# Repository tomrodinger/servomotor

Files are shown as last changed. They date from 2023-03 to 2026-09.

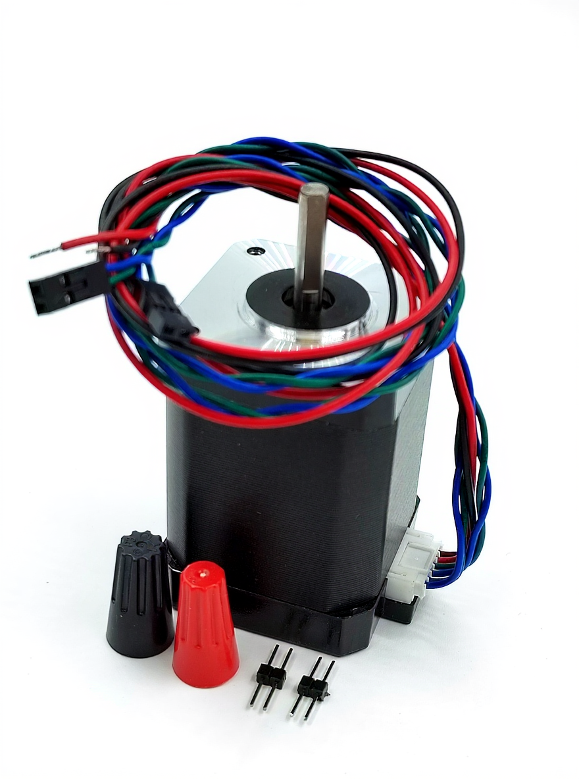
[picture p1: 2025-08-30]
Pictures/servomotor3/ai edited/flux-1-kontext-dev_make_the_background_.png

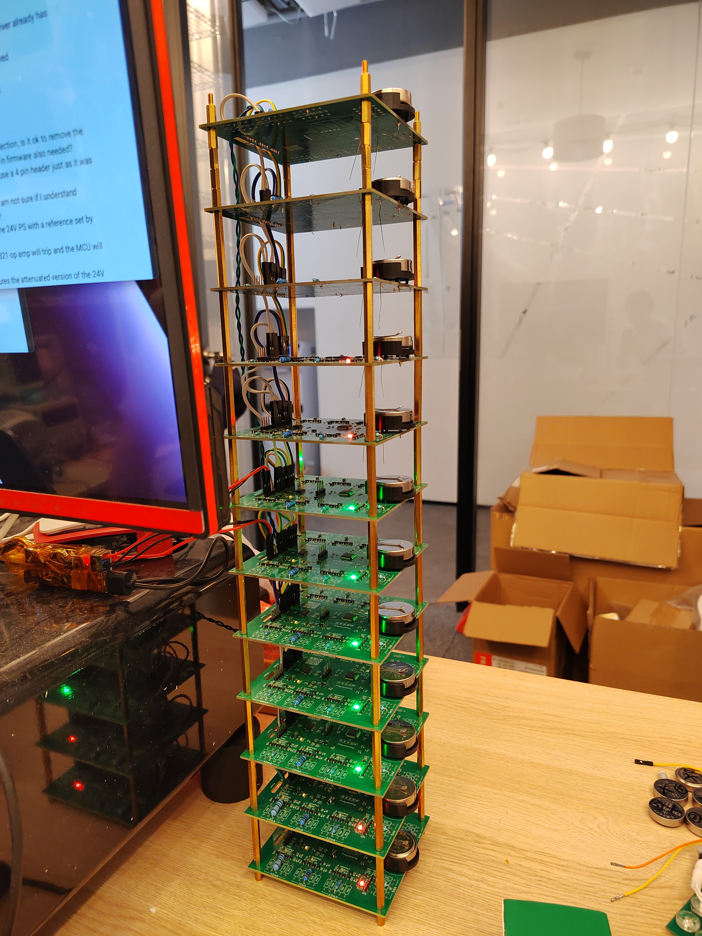
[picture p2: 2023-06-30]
Pictures/coin_cell_tester/side2.jpg

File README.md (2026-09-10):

<p align="center">
  Gearotons M17 servomotor family: M17-60, M17-48, M17-40, M17-34
</p>

# Gearotons M17 — an open-source servomotor you can talk to

The M17 is a NEMA-17 **integrated servomotor**: motor, closed-loop driver, motion controller and
magnetic encoder in one unit. It daisy-chains over RS-485, ships with Python and Arduino libraries,
and has a first-party [MCP server](https://github.com/Gearotons/servomotor-mcp) so an AI assistant
(Claude Desktop, Claude Code, Cursor, …) can drive real motors from plain English.

Hardware, firmware and software are all in this repository under the MIT license.

| | M17-34 | M17-40 | M17-48 | M17-60 |
|---|---|---|---|---|
| Length | 33.5 mm | 40.1 mm | 48.7 mm | 59.7 mm |
| Holding torque | 0.28 N·m | 0.42 N·m | 0.55 N·m | 0.65 N·m |
| Weight | 210 g | 285 g | 360 g | 470 g |

All sizes: 12–24 V, up to ~1.1 A, up to 560 RPM, closed-loop 32 kHz control, RS-485 at 230400 baud,
64-bit unique ID + one-byte alias per motor, standard NEMA-17 mount. Indoor use (IP20).

**Buy one:** [gearotons.com](https://gearotons.com) (from $20; ships worldwide from Shenzhen).
**Documentation:** [9o.at/M17_1.5](https://9o.at/M17_1.5) ·
[Datasheet (PDF)](servomotor_datasheets/datasheet_latest_en.pdf) ·
[Python API](API_documentation/M17_servomotor_Python_API_documentation.md) ·
[Arduino API](API_documentation/M17_servomotor_Arduino_API_documentation.md)

## Quick start (Python)

```bash
pip install servomotor
```

```python
import time, servomotor

servomotor.open_serial_port()                      # prompts for the USB–RS-485 adapter the first time
m = servomotor.M3("X", time_unit="seconds", position_unit="shaft_rotations")
m.enable_mosfets()
m.trapezoid_move(1.0, 1.0)                         # one full turn, in one second
time.sleep(1.1)
m.disable_mosfets()
servomotor.close_serial_port()
```

That is [`python_programs/example_trapezoid_move.py`](python_programs/example_trapezoid_move.py).
Units are yours to choose (degrees, rotations, radians, encoder counts; seconds or milliseconds) —
the library converts. No STEP/DIR timing, no microstep configuration.

## Quick start (Arduino / ESP32)

Install the **Servomotor** library by Gearotons from the Arduino Library Manager, or from
[`Arduino_library/`](Arduino_library/). Wire the board's UART to an RS-485 transceiver, then:

```cpp
#include <Servomotor.h>

void setup() {
  Servomotor motor('X', Serial1);                  // alias 'X'; the port opens on first use
  motor.setPositionUnit(PositionUnit::SHAFT_ROTATIONS);
  motor.setTimeUnit(TimeUnit::SECONDS);
  motor.enableMosfets();
  motor.trapezoidMove(2.0f, 3.0f);                 // two rotations over three seconds
  delay(4000);
  Serial.println(motor.getPosition());             // where it actually is, from the encoder
}
void loop() {}
```

That is a trimmed [`Arduino_library/example_one_move.cpp`](Arduino_library/example_one_move.cpp)
(the full file adds the ESP32 RS-485 pin definitions).

## Quick start (talk to it)

```bash
uvx --from servomotor-mcp servomotor-mcp        # runs with a simulated motor if no hardware is attached
```

Add it to Claude Desktop or run `claude mcp add gearotons-motor -- uvx --from servomotor-mcp servomotor-mcp`,
then ask: *"Find my motors, then move the one on the bench to 90 degrees and tell me where it ended up."*
Details and the full tool list: [Gearotons/servomotor-mcp](https://github.com/Gearotons/servomotor-mcp).

<p align="center">
  Claude Code driving a real M17 over MCP: find the motor, turn it two rotations, back, read the encoder
</p>
<p align="center"><a href="https://github.com/Gearotons/servomotor-mcp/releases/download/v0.3.1/M17-claude-code-demo.mp4">▶ 50-second video: the real motor and this session side by side</a> (recorded 2026-09-09 on a bench M17).</p>

<p align="center">
  Wiring: computer, USB to RS-485 adapter, two daisy-chained M17 motors, 12–24 V supply
</p>

## What is in this repository

| Folder | Contents |
|---|---|
| [`firmware/`](firmware/) | Motor firmware (STM32G0), plus [`bootloader_STM32G030/`](bootloader_STM32G030/) and [`bootloader_STM32G031/`](bootloader_STM32G031/) |
| [`PCB/`](PCB/) | Schematics, board layouts and 3D (STEP) models of the controller board |
| [`python_programs/`](python_programs/) | The `servomotor` Python library source, examples, test and characterisation scripts |
| [`Arduino_library/`](Arduino_library/) | The Arduino/ESP32 C++ library and examples |
| [`API_documentation/`](API_documentation/) | Generated Python and Arduino API references (Markdown and PDF) |
| [`servomotor_datasheets/`](servomotor_datasheets/) | Datasheet sources and PDFs (EN, DE, ES, FR, IT, PT), dimension drawings |
| [`production_test_system/`](production_test_system/), [`motor_tests/`](motor_tests/) | How we test motors before they ship |
| [`marketting_page/`](marketting_page/) | Source of the gearotons.com product page |

The command set is data-driven: every firmware command is defined once in
[`motor_commands.json`](python_programs/servomotor/motor_commands.json) and the Python library, the Arduino library and the MCP server are generated
from it, so they always agree.

## Where the M17 is not the right tool

Direct-drive torque tops out at 0.65 N·m (gear it or go up a frame size for more), it is IP20 and
indoor-only, and it is not a STEP/DIR drop-in for an existing 3D-printer board — it wants a serial
bus and a host that sends it moves. We would rather you know that before you buy.

## Community and support

Questions and builds: [GitHub Discussions](https://github.com/tomrodinger/servomotor/discussions) ·
email [info@gearotons.com](mailto:info@gearotons.com). Issues and pull requests welcome — the whole
stack is here to be read, modified and improved.

Built and assembled by Gearotons in Shenzhen. MIT license — see [LICENSE](LICENSE).

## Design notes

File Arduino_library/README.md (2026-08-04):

# Project Overview

> **Documentation Note**: All project documentation is maintained in this README.md file. Whenever documentation is mentioned or requested, it refers to updates or additions to this file.

This project provides a C++ library for controlling servo motors on both embedded platforms (Arduino, ESP32-C3, etc.) and desktop environments (macOS, etc.). It includes:

- **Minimal Arduino emulator** for desktop testing (`ArduinoEmulator.h`).
- **Auto-generated unit conversions** for positions, velocities, times, temperatures, etc. (`AutoGeneratedUnitConversions.*`).
- **Servomotor** class for motor control with advanced features like calibration, homing, e-stop, etc.
- **Example test programs**: `test_one_move.cpp`, `test_unit_conversions.cpp`, and `test_get_temperature.cpp`.

## Autogeneration of Parts of the Source Code

The library includes several Python scripts for code generation and maintenance:

- `generate_unit_conversion_code.py`: Generates unit conversion code from a JSON configuration
- `generate_command_code.py`: Generates command interface code

## File List and Descriptions

Below is an updated overview of the key files after renaming and restructuring:

| File | Description |
|---|---|
| **ArduinoEmulator.h** | Emulates Arduino's `Serial`, `delay()`, etc. for desktop builds. |
| **AutoGeneratedUnitConversions.h / .cpp** | Functions to convert between various units (time, position, velocity, acceleration, etc.). |
| **Commands.h** | Autogenerated list of servo command IDs. |
| **Communication.h / .cpp** | Simple `Communication` class for sending/receiving commands (stubbed for testing). |
| **DataTypes.h / .cpp** | Definitions of data type structures and bounds. |
| **Utils.h / .cpp** | Helper utilities for endianness, packing, and general-purpose functionality. |
| **Servomotor.h / .cpp** | Main servo control class with features like calibration, homing, e-stop, etc. |
| **test_one_move.cpp** | Minimal example demonstrating a single trapezoid move (2 rotations over 3 seconds). |
| **test_unit_conversions.cpp** | Desktop test verifying unit-conversion logic in `AutoGeneratedUnitConversions.*`. |
| **test_get_temperature.cpp** | Example demonstrating how to read temperature from the motor. |
| **test_emergency_stop.cpp** | Test for emergency stop functionality to ensure proper queue clearing and MOSFET disabling. |
| **test_move_with_velocity.cpp** | Test for moveWithVelocity functionality with different units (rotations, degrees, encoder counts). |
| **test_enable_disable_mosfets.cpp** | Test for enabling and disabling MOSFETs. |
| **test_one_move_two_motors.cpp**  | Example demonstrating control of two motors simultaneously. |

## Architecture

1. **Unit Conversion Module**  
   - Centralizes all unit transformations in `AutoGeneratedUnitConversions.*`, ensuring consistency.
   - Supports various units:
     - Position: SHAFT_ROTATIONS, DEGREES, RADIANS, ENCODER_COUNTS
     - Time: SECONDS, MILLISECONDS, MINUTES, TIMESTEPS
   - Automatic conversion between user units and internal units (encoder counts and timesteps)

3. **Communication Module**  
   - `Communication.cpp` is a lightweight stub for sending commands and reading responses. It can be extended or replaced with a hardware-specific protocol (RS-485, UART, etc.).

4. **Servo Control Class**  
   - **`Servomotor`** provides:
     - Automatic unit conversions between user units and internal units
     - Detailed debug output for all operations
     - Automatic serial port initialization
     - User-friendly interface for motor control

5. **Testing on Desktop vs. Arduino**  
   - If `ARDUINO` macros are defined, `<Arduino.h>` is used for real hardware.  
   - Otherwise, `ArduinoEmulator.h` provides stubs for Serial/delay so the same code builds on desktop.  
   - **Test programs** can be built via a standard C++ compiler on desktop or compiled as `.ino`/C++ sources on an Arduino platform.

## RS485 Communication Protocol

The library implements a robust RS485 communication protocol for reliable communication between a controller (master) and one or more devices (slaves). The protocol supports both standard addressing (using device aliases) and extended addressing (using 64-bit Unique IDs).

### Packet Format

All packets follow this basic structure:

1. **Size Bytes**: First byte(s) indicating total packet size
   - For sizes 1-127: Single byte containing size (left-shifted 7 bits with LSB=1)
   - For sizes >127: Three bytes
     - First byte: `0xFF` (encoded value of 127 with LSB=1)
     - Two additional bytes: Little-endian 16-bit size

2. **Address Bytes**:
   - **Standard Addressing**: Single byte containing device alias
     - `255` (`ALL_ALIAS`): Broadcasts to all devices
     - `254` (`EXTENDED_ADDRESSING`): Indicates extended addressing mode
     - `253` and `252` are not allowed because they are used to indicate responses (see below)
     - `0-251`: Normal device aliases
   - **Extended Addressing**: When address byte is `254`, next 8 bytes contain 64-bit Unique ID (little-endian)

3. **Command Byte**: 8-bit command identifier

4. **Payload Data**: Variable length data specific to the command

5. **CRC32**: Optional 4-byte CRC32 checksum (enabled by default but can be disabled)

### Response Format

Responses from devices follow this structure:

1. **Size Bytes**: Same format as command packet

2. **Response Character**: Single byte indicating response and CRC32 state
   - `253` (`RESPONSE_CHARACTER_CRC32_ENABLED`): Response from device with CRC32 enabled
   - `252` (`RESPONSE_CHARACTER_CRC32_DISABLED`): Response from device with CRC32 disabled

3. **Command Byte**: 8-bit value indicating status
   - `0`: Success and there is no firther data in the response
   - `1`: Success and there is some further data in the response
   - Other values: Currently not used and reserved for future use

4. **Payload Data**: Variable length response data

5. **CRC32**: Optional 4-byte checksum (enabled by default but can be disabled)

### CRC32 Implementation

CRC32 checksums provide additional data integrity verification:

- Uses polynomial 0xEDB88320
- Initialized to 0xFFFFFFFF
- Calculated over entire packet contents (including size, address/response character, command, and payload bytes)
- Final value is inverted to get the final CRC32 value
- The CRC32 calculation gives the same result as Pythons zlib.crc32() or binascii.crc32() functions

- Control:
  - Enabled by default after device reset
  - Can be enabled or disabled on a per-device basis by sending a `CRC32_CONTROL_COMMAND`
  - The response has encoded in it whether the device has appended a CRC32 in the response or not
  - Error statistics can be retrieved by issuing a `GET_CRC32_ERROR_COUNT_COMMAND` to the device

### Error Handling

The protocol includes robust error handling with specific error codes. The `Communication` class functions (particularly `getResponse`) return specific negative error codes on failure, or `COMMUNICATION_SUCCESS` (0) on success:

- `COMMUNICATION_ERROR_TIMEOUT` (-1): Timed out waiting for reply bytes. The 1-second budget covers the WHOLE reply, not each byte, and the stages it can expire in are: the first size byte, the extended size bytes, the response character, the device error byte, the payload, and the CRC32 (if enabled). A broadcast (alias 255) also produces this, because broadcasts are never answered.
- `COMMUNICATION_ERROR_DATA_WRONG_SIZE` (-2): The reply's payload length did not match what the command expects
- `COMMUNICATION_ERROR_BAD_RESPONSE_CHAR` (-3): The response character byte was not `RESPONSE_CHARACTER_CRC32_ENABLED (253)` or `RESPONSE_CHARACTER_CRC32_DISABLED (252)`
- `COMMUNICATION_ERROR_BUFFER_TOO_SMALL` (-5): Your buffer was smaller than the payload the device sent. For the variable-length calls the required size is reported back through `actualSize`, so you can resize and retry
- `COMMUNICATION_ERROR_CRC32_MISMATCH` (-6): Calculated CRC32 of the received response did not match the received CRC32 value (when CRC enabled)
- `COMMUNICATION_ERROR_BAD_FIRST_BYTE` (-7): The first byte of a received packet did not have LSB=1, indicating a format error or corrupted data
- `COMMUNICATION_ERROR_PACKET_TOO_SMALL` (-9): The declared packet length was too small to be a valid reply

Two further macros exist in `Communication.h` but are never returned by any code path, so do not write handlers for them: `COMMUNICATION_ERROR_BAD_STATUS_CHAR` (-4) and `COMMUNICATION_ERROR_BAD_THIRD_BYTE` (-8). (-8 in particular described a "Command Byte" in the response; replies contain no command byte.)

### Buffer Handling

When using the Arduino library's `getResponse` function for commands that do not return any payload data, `nullptr` can be passed as the buffer. The library will still receive and validate the full response (including CRC32 check if applicable) but will not attempt to copy the (empty) payload.

### Command Processing Flow

1. Controller sends command packet
2. Device receives and processes command
3. Device sends response packet (if required)
4. Controller receives and validates response

### Communication Class Methods

The `Communication` class provides the following key methods:

- `Communication(HardwareSerial& serialPort)`: Constructor, requires a `HardwareSerial` port (e.g., `Serial1`)
- `sendCommand(uint8_t alias, uint8_t commandID, const uint8_t* payload, uint16_t payloadSize)`: Sends a command using standard alias addressing
- `sendCommandByUniqueId(uint64_t uniqueId, uint8_t commandID, const uint8_t* payload, uint16_t payloadSize)`: Sends a command using extended 64-bit Unique ID addressing
- `getResponse(uint8_t* buffer, uint16_t bufferSize, uint16_t& receivedSize)`: Waits for, receives, validates, and processes a response packet from a device. Returns `COMMUNICATION_SUCCESS` or a negative error code. Fills `buffer` with payload and `receivedSize` with payload length on success
- `enableCRC32() / disableCRC32()`: Manages the library's expectation of whether CRC32 should be included in *outgoing* commands. Note: The library automatically updates its internal CRC state based on the response character received from the device
- `isCRC32Enabled()`: Returns true if the library currently expects CRC32 to be used
- `flush()`: Discards any unread incoming serial data and waits for outgoing data to finish transmitting

## Installation

1. Download the Arduino library
2. Import it into the Arduino IDE
3. Include the library in your project by including "Servomotor.h"

## Example Usage

A typical Arduino `.ino` or `.cpp` file might look like:

```cpp
#include "Servomotor.h"

void setup() {
  Serial.begin(115200);  // For debug output

  // Create a Servomotor instance (note the lower-case 'm' - ServoMotor with a
  // capital M is a different, unrelated Arduino library)
  Servomotor motor('X', Serial1);  // Initialize with alias 'X' and Serial1 port
  
  // Set desired units (debug output will show the conversions)
  motor.setPositionUnit(PositionUnit::SHAFT_ROTATIONS);
  motor.setTimeUnit(TimeUnit::SECONDS);
  
  // Move 2 rotations over 3 seconds
  motor.trapezoidMove(2.0f, 3.0f);
}

void loop() {
  // ...
}
```

The debug output will show:
```
[Motor] Initialized with standard addressing, Alias: 88
[Motor] setPositionUnit called
[Motor] setTimeUnit called
[Motor] trapezoidMove called.
  displacement in chosen unit: 2.00
  duration in chosen unit: 3.00
[Motor] trapezoidMoveRaw called.
```

Two things to note about this output. The alias prints as its decimal character
code, so `'X'` appears as `88`. And a unit-converting call such as
`trapezoidMove()` prints several lines, because the wrapper echoes each argument
and then calls the internal `...Raw()` variant, which prints as well.

These messages are printed unconditionally by every command; there is currently no
compile-time flag to switch them off. Bear that in mind before putting a command
inside a fast polling loop.

### Checking whether a command actually worked

No command method returns a success flag. Each one records the outcome of its last
exchange with the motor, and you read it with `getError()`:

```cpp
motor.enableMosfets();
if (motor.getError() != 0) {
  Serial.print("enableMosfets failed, getError() = ");
  Serial.println(motor.getError());
}
```

`getError()` returns `0` on success, a **positive** value that is the motor's own
fatal error code, or a **negative** value for a host-side communication failure
(`-1` is a timeout: wrong alias, wrong pins, motor unpowered, or motor in the
bootloader). This matters because a motor that has latched a fatal error disables
itself and silently ignores every later command except *Get status* and
*System reset* — your sketch keeps running normally and the motor simply stops
moving.

Watch out for one trap: when a read fails, the getters return a zero-initialised
default rather than an error value. `Serial.println(motor.getHallSensorPosition())`
printing `0.00` can mean "the call failed", not "the shaft is at zero". Always check
`getError()` before trusting a returned value.

See the *Arduino Essentials* section of the Servomotor Arduino API documentation
for the full treatment, including the recommended startup sequence.

### Important Usage Notes

**Using moveWithVelocity and moveWithAcceleration:**
When using moveWithVelocity or moveWithAcceleration, you must queue a second move to stop the motor properly. If the final velocity is not zero when the queue becomes empty, the motor will trigger a fatal error.

Example with moveWithVelocity:
```cpp
// First move at desired velocity
motor.moveWithVelocity(2.0f, 1.0f);  // 2 rotations/sec for 1 second

// Then queue a stop command
motor.moveWithVelocity(0.0f, 0.1f);  // 0 rotations/sec for 0.1 seconds
```

Example with moveWithAcceleration:
```cpp
// First move with positive acceleration
motor.moveWithAcceleration(2.0f, 1.0f);  // 2 rotations/sec² for 1 second

// Then queue a move with negative acceleration to stop
motor.moveWithAcceleration(-2.0f, 1.0f);  // -2 rotations/sec² for 1 second
```

**Using multiMove for Complex Motion Sequences:**
The multiMove function allows you to queue multiple velocity and acceleration moves in a single command. This is useful for creating complex motion sequences without having to send multiple commands.

There are two versions of the multiMove function:
- `multiMove`: Handles unit conversions based on your configured units
- `multiMoveRaw`: Uses raw internal units without conversion

The library provides two structures for defining move sequences:
1. `multiMoveListConverted_t`: For user-friendly units with floating-point values
   ```cpp
   typedef struct {
       float value;       // velocity or acceleration in user units
       float duration;    // duration in user units (seconds, milliseconds, etc.)
   } multiMoveListConverted_t;
   ```

2. `multiMoveList_t`: For raw internal units
   ```cpp
   typedef struct {
       int32_t value;     // acceleration or velocity value (internal units)
       uint32_t timeSteps; // duration in time steps (internal units)
   } multiMoveList_t;
   ```

Example with multiMove (using user units):
```cpp
// Create a sequence of moves
const uint8_t multiMoveCount = 4;
uint32_t multiMoveTypes = 0b1001;  // 1st and 4th are velocity moves, 2nd and 3rd are acceleration moves

// Create move list with user units
multiMoveListConverted_t multiMoveList[multiMoveCount] = {
    {2.0f, 1.0f},    // Velocity move: 2 rot/sec for 1 sec
    {2.0f, 1.0f},    // Acceleration move: 2 rot/sec² for 1 sec
    {-2.0f, 1.0f},   // Acceleration move: -2 rot/sec² for 1 sec
    {0.0f, 0.1f}     // Velocity move: 0 rot/sec for 0.1 sec (stop)
};

// Execute the multi-move sequence with automatic unit conversion
motor.multiMove(multiMoveCount, multiMoveTypes, multiMoveList);
```

Example with multiMoveRaw (using internal units):
```cpp
// Create a sequence of moves
const uint8_t multiMoveCount = 2;
uint32_t multiMoveTypes = 0b11;  // Both are velocity moves

// Create move list with internal units
// For velocity: CONVERSION_FACTOR_ROTATIONS_PER_SECOND = 109951162.777600005f
// For time: CONVERSION_FACTOR_SECONDS = 31250.000000000f
multiMoveList_t multiMoveList[multiMoveCount] = {
    {219902325, 31250},  // Velocity move: 2 rot/sec for 1 sec in internal units
    {0, 3125}            // Velocity move: 0 rot/sec for 0.1 sec in internal units
};

// Execute the multi-move sequence with raw units
motor.multiMoveRaw(multiMoveCount, multiMoveTypes, multiMoveList);
```

The moveTypes parameter is a 32-bit number where each bit specifies the type of move:
- 0: MOVE_WITH_ACCELERATION
- 1: MOVE_WITH_VELOCITY

For example, 0b1001 means the 1st and 4th moves are velocity moves, while the 2nd and 3rd are acceleration moves.

The last move in a sequence should always set the motor's velocity to 0 for a period of time (e.g., 0.1 seconds) to allow the motor to stop properly. Otherwise, the motor will enter a fatal error state when the queue becomes empty with a non-zero velocity on the motor.

**Expected Position Calculation for Complex Sequences:**
When using a combination of velocity and acceleration moves, the final position can be calculated as follows:

1. Velocity move: distance = velocity × duration
2. Acceleration move:
   - Starting from a non-zero velocity: distance = (initial_velocity × duration) + (0.5 × acceleration × duration²)
   - Final velocity = initial_velocity + (acceleration × duration)

For example, in a sequence like:
```cpp
multiMoveListConverted_t moves[4] = {
    {2.0f, 1.0f},    // Velocity move: 2 rot/sec for 1 sec
    {2.0f, 1.0f},    // Acceleration move: 2 rot/sec² for 1 sec
    {-2.0f, 1.0f},   // Acceleration move: -2 rot/sec² for 1 sec
    {0.0f, 0.1f}     // Velocity move: 0 rot/sec for 0.1 sec (stop)
};
```

The expected position calculation would be:
1. Velocity move: 2 rot/sec × 1 sec = 2 rotations
2. Acceleration move: Starting velocity 2 rot/sec, accelerating at 2 rot/sec²
   - Displacement = (2 rot/sec × 1 sec) + (0.5 × 2 rot/sec² × 1 sec²) = 2 + 1 = 3 rotations
   - Final velocity = 2 + (2 × 1) = 4 rot/sec
3. Acceleration move: Starting velocity 4 rot/sec, decelerating at 2 rot/sec²
   - Displacement = (4 rot/sec × 1 sec) - (0.5 × 2 rot/sec² × 1 sec²) = 4 - 1 = 3 rotations
   - Final velocity = 4 - (2 × 1) = 2 rot/sec
4. Velocity move: 0 rot/sec for 0.1 sec (stop)
   - Displacement = 0 rotations

Total displacement: 2 + 3 + 3 + 0 = 8 rotations

### Testing

The library's test suite lives in **`Servomotor_TestSuite_ESP32S3/`** (see its
README for full details). It contains ~37 modular tests (`tm_*.cpp`, one per
command group, ~580 assertions) that build TWO ways from the same sources:

1. **On-device (primary):** all modules compile into one ESP32-S3 firmware that
   runs natively on the Gearotons ESP32-S3 RS485 controller — one test per
   boot, the ESP32 resets between tests, progress + pass/fail statistics
   persist in NVS, and a serial CLI triggers tests over the debug link.

   ```bash
   cd Servomotor_TestSuite_ESP32S3
   ./flash_suite.sh                 # refresh installed lib + compile + flash
   python3 run_suite_mac.py         # start a full run and collect results
   python3 run_suite_mac.py --only 5   # run a single test by index
   ```

2. **Host mode:** the same modules compile on a desktop against the Arduino
   emulator (`ArduinoEmulator.h`) and talk to a motor through any USB-RS485
   port — no flashing needed, useful for quick iteration and for testing a
   multi-motor bus from the desktop:

   ```bash
   cd Servomotor_TestSuite_ESP32S3
   ./build_host_suite.sh
   ./host_suite /dev/cu.usbserial-XXXX <16-hex-unique-id> all
   ./host_suite /dev/cu.usbserial-XXXX <16-hex-unique-id> multimove   # one test
   ```

Tests marked with known-bug annotations in `test_registry.cpp` assert the
CORRECT behavior and are expected to fail until those library bugs are fixed;
the suite summary counts them separately (`unexpected=0` means a clean run).

## TODO / Upcoming Changes

1. **Unit Conversion Tests to Implement (in order of priority)**
   - test_position_conversions.cpp - Test position unit conversions in:
     - trapezoidMove / trapezoidMoveRaw
     - goToPosition / goToPositionRaw
     - getPosition / getPositionRaw
     - getHallSensorPosition / getHallSensorPositionRaw
     - getComprehensivePosition / getComprehensivePositionRaw
     - Multimove
   
   - test_time_conversions.cpp - Test time unit conversions in:
     - getCurrentTime / getCurrentTimeRaw
     - trapezoidMove (duration parameter)
     - goToPosition (duration parameter)
     - moveWithVelocity (duration parameter)
   
   - test_velocity_conversions.cpp - Test velocity unit conversions in:
     - setMaximumVelocity / setMaximumVelocityRaw
     - moveWithVelocity / moveWithVelocityRaw
   
   - test_acceleration_conversions.cpp - Test acceleration unit conversions in:
     - setMaximumAcceleration / setMaximumAccelerationRaw
     - moveWithAcceleration / moveWithAccelerationRaw
   
   - test_current_conversions.cpp - Test current unit conversions in:
     - setMaximumMotorCurrent / setMaximumMotorCurrentRaw
   
   - test_temperature_conversions.cpp - Test temperature unit conversions in:
     - getTemperature / getTemperatureRaw
   
   - test_limits_conversions.cpp - Test limit unit conversions in:
     - setSafetyLimits / setSafetyLimitsRaw
     - setMaxAllowablePositionDeviation / setMaxAllowablePositionDeviationRaw

3. **Code Generation Enhancements**
   - ✅ Improve the autogeneration program that creates Servomotor.cpp and Servomotor.h
   - ✅ Make the code generation process more maintainable and flexible
   - ✅ Fix the conversion factors for current and voltage in the unit_conversions_M3.json file. Currently, these factors are missing or incorrect, resulting in a factor of 1.0 being used.

3. **Fix Some Problems With Servomotor.cpp, or Rather the Program that Generates this File, Which is generate_command_code.py**
   - ✅ getComprehensivePosition obviously will return zeros, which is wrong. Seems the autogeneration program does not know how to convert this
   - ✅ getMaxPidError has the same problem

4. **Fix the Multimove Function**
   - ✅ Fixed the moveList parameter type by defining a struct for move commands:
     ```cpp
     typedef struct {
         int32_t value;  // acceleration or velocity value (internal units)
         uint32_t timeSteps;  // duration in time steps (internal units)
     } multiMoveList_t;
     ```
   - ✅ Added a new struct for user-friendly units with floating-point values:
     ```cpp
     typedef struct {
         float value;  // velocity or acceleration in user units
         float duration;  // duration in user units (seconds, milliseconds, etc.)
     } multiMoveListConverted_t;
     ```
   - ✅ Implemented two versions of the multiMove function:
     - `multiMoveRaw`: Uses raw internal units without conversion
     - `multiMove`: Handles unit conversions based on configured units
   - ✅ Created example_multi_move.cpp to demonstrate how to use the multiMove function with a sequence of moves
   - ✅ Fixed the expected behavior calculation in example_multi_move.cpp to correctly account for velocity continuity between moves
   - ✅ Verified that the implementation works correctly with unit conversions
   - ✅ Created test_multi_move.cpp test program that extensively tests the multiMove and multiMoveRaw functions with all units for velocity, acceleration, and time
   - ✅ Added helper functions for calculating appropriate delay times for both user units and internal units
   - ✅ Updated documentation with detailed information about the multiMove functions, structures, and expected position calculations
   - ✅ Updated the autogeneration program (../autogeneration/generate_command_code.py) to correctly generate the Servomotor.h and Servomotor.cpp files with proper handling of list_2d type parameters in wrapper functions.
   - ✅ Verified that test_multi_move.cpp compiles and passes after the autogeneration program changes. All tests pass in fact.

5. ✅ **Rename ServomotorCommands.cpp to Servomotor.cpp** (Completed)
   - ✅ Renamed ServomotorCommands.h to Servomotor.h
   - ✅ Updated all tests and programs to use Servomotor.h instead
   - ✅ Updated the generate_command_code.py script to generate the updated filenames

6. **test_unit_conversions test fails, need to fix**
   - one test related to testAccelerationConversions() fails

7. ✅ **Make sure that the copy_stuff_to_Arduino.sh script copies all relevant file for the Arduino library to work**
    - ✅ Updated the script to only copy core library files
    - ✅ Added proper handling of example files (example_one_move.cpp and example_one_move_two_motors.cpp)
    - ✅ Created proper Arduino library directory structure with src/ and examples/ folders

8. **Test the Arduino library on an actual Arduino board such as ESP32-C3**
   - ✅ see if it compiles
   - ✅ see if it can control an actual motor

9. **Create more Arduino examples**
    - Create additional simple examples for common use cases
    - Ensure examples demonstrate best practices for using the library
    - Consider examples for different motor control scenarios

10. **Launch this Arduino library into the Arduino marketplace**
    - Anyone on the internet familiar with the Arduino IDE should be able to get it and easily use it

11. **Revamp the test_unit_conversion.cpp test**
    - this test should do unit conversions in one direction (given unit to internal unit) and in the other direction (internal to given unit)
    - it should check the converted value against the validation numbers in the ../python_programs/servomotor/unit_conversions_M3.json file
    - the test should read in the above json file on the fly to get all units to be tested as well as the validation values

12. **Clean up magic numbers in the tests**
   - ✅ many values look like magic numbers but are just a multiple of the MICROSTEPS_PER_ROTATION, so we should place a #define in the test for the MICROSTEPS_PER_ROTATION and then derive validation number based on this

13. **Revamp how magic numbers are defined in the AutoGeneratedUnitConversions.x files**
   - ✅ Magic numbers should be moved to AutoGeneratedUnitConversions.h and should follow a simular naming convention as in the source file where the data is taken from, which is from the json file that is given as a parameter to generate_unit_conversion_code.py, where currently that file is ../python_programs/servomotor/unit_conversions_M3.json
   AutoGeneratedUnitConversions.cpp should be refined to use the #defines instead of holding the magic numbers within the functions.
   - ✅ For conversion that are more complex than multiplying or dividing by a scaling factor (temperature conversion being an exmaple), we need to add another field to ../python_programs/servomotor/unit_conversions_M3.json where we indicate an additional factor that is added. Please propse the new structure of the json file and let me confirm it.
   - ✅ Since ../python_programs/servomotor/unit_conversions_M3.json is also an autogenerated program, we will need to modify the program that autogenerates this, which is ../python_programs/servomotor/autogenerate_unit_conversions.py

14. **Unify autogeneration programs into one main executable**
   - ✅ The current autogeneration programs are these:
      ../python_programs/servomotor/autogenerate_unit_conversions.py
      generate_unit_conversion_code.py
      generate_command_code.py
      ../firmware/generate_lookup_tables/BLDC_sin_lookup_table.py
      ../firmware/generate_lookup_tables/compute_hall_sensor_constants.py (this program needs to have a new parameter to specify if new weights should be calculated or skipped)
   - ✅ These should be moved to a separate directory in the root called autogeneration. All autogeneration programs should be moved into there.
   - ✅ a single executable called autogenerate.py should be created that essentially runs all of the other programs.
   - Optionally, the other programs should become Python modules that are called by importing them into the autogenerate.py program

15. **The Aurduino Library should have a optional verbose mode**
   - Currently by deafault it is too verbose
   - Need a flag that is configurable by the user at compile time
   - The flag shoild affect hot Servomotor.cpp is compiled into the Arduino project
   - We can modify Servomotor.cpp manually at first to try out method but later we must modify the autogeneration program, which is ../autogeneration/generate_command_code.py

16. **Remove the commandID magic numbers from Servomotor.cpp**
   - ✅ For example, this line:
       const uint8_t commandID = 14;
     should become:
       const uint8_t commandID = CMD_HOMING;
     after the change.
   - ✅ Make sure to change the autogeneration program called ../autogeneration/generate_command_code.py and not Servomotor.cpp directly
   - ✅ Make sure that all tests pass after the change

## License

This library is released under the MIT License. See the LICENSE file for details.

## Author

Tom Rodinger (tom@gearotons.com)

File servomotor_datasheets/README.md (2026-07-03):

# Servomotor Datasheet Generator

The [`generate_datasheet.py`](generate_datasheet.py:53) program is a modular PDF generation system that creates professional datasheets for M17 Series Servomotors using ReportLab.

## Core Functionality
- Generates versioned PDF datasheets with automatic version management via [`versioning.py`](versioning.py:4)
- Creates both versioned files (e.g., `datasheet_v1.9_en.pdf`) and a `datasheet_latest_<lang>.pdf` copy per language (all output filenames are kept to 25 characters or less)
- Multilingual: English, German, French, Spanish, Italian, Portuguese
- Uses modular architecture with separate files for different content sections

## Generating

```bash
python3 generate_datasheet.py              # English only
python3 generate_datasheet.py --lang de    # one language
python3 generate_datasheet.py --all        # all languages
```

## Translations

All user-facing text goes through [`i18n.py`](i18n.py)'s `tr()` and is looked up in
`translations/<lang>.json`, keyed by the (whitespace-normalized) **English text itself**.
English is the single source of truth: edit English text in the code, the `.txt` source
files, or `motor_commands.json` descriptions, and the changed strings automatically become
*missing* in every language (the generator falls back to English for them and can never
show a stale translation).

Update workflow after changing any English text:
1. `python3 generate_datasheet.py --all` — prints a warning per language and writes the
   untranslated strings to `translations/missing_<lang>.json` (exit code is non-zero when
   translations are incomplete)
2. Translate the entries in each `missing_<lang>.json` and merge them into
   `translations/<lang>.json` (asking Claude to do this works well); optionally prune keys
   that no longer exist
3. Re-run `python3 generate_datasheet.py --all` — the warnings disappear and the
   `missing_*.json` files are removed

Notes:
- Translations must only use Latin-1/cp1252 characters (the PDF uses built-in Helvetica);
  adding e.g. Polish would require embedding a Unicode TTF font first
- Command names, unit names, URLs, and code samples intentionally stay in English (they
  match the Python/Arduino APIs); command *descriptions* and everything else is translated
- To add a language: add its code to `LANGUAGES` in [`i18n.py`](i18n.py), run
  `generate_datasheet.py --lang <code>`, and translate the generated `missing_<code>.json`
  into `translations/<code>.json`

## Key Components
- **Content Management**: [`content.py`](content.py:48), [`specs.py`](specs.py:13), [`protocol.py`](protocol.py), [`indicators.py`](indicators.py) handle different datasheet sections
- **Libraries**: [`python_library.py`](python_library.py), [`arduino_library.py`](arduino_library.py) document programming interfaces
- **Styling**: [`styles.py`](styles.py) provides consistent PDF formatting and corporate branding
- **Utilities**: [`utils.py`](utils.py) handles image processing and table creation
- **Company Info**: [`company_info.py`](company_info.py), [`open_source.py`](open_source.py) add corporate and licensing information

## Output Features
- Professional layout with company branding (Gearotons logo)
- Technical specifications tables for M17-40, M17-48, and M17-60 models
- Dimensional drawings, connection diagrams, and installation instructions
- Communication protocol documentation and programming examples
- Automatic page numbering and footer generation

**Dependencies**: ReportLab, Pillow, NumPy (see [`requirements.txt`](requirements.txt:1))

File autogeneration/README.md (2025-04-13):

# Code Autogeneration System

This document describes the code autogeneration system used to generate command-related code from JSON definitions.

## Core Principles

1. **Data-Driven Code Generation**: All command-specific code is derived from JSON data files, not hardcoded in templates or generation scripts.
2. **No Command-Specific Logic**: Generation modules must NEVER contain ANY hardcoded command names or special-case handling for specific commands.
3. **Separation of Templates and Generation Logic**: Templates define structure, generation modules produce content.
4. **Type-Based Processing**: Processing logic should be based on data types and patterns, not on specific command names.

## File Structure

The autogeneration system consists of:

1. **JSON Data Files**:
   - `motor_commands.json`: Contains command definitions, parameters, and types
   - `data_types.json`: Contains data type definitions and sizes

2. **Generation Modules**:
   - `generate_command_methods.py`: Generates method declarations for commands
   - `generate_payload_structures.py`: Generates payload and response structure declarations
   - Other modules for generating specific parts of the code

3. **Templates**:
   - `Servomotor.h.template`: Template for Servomotor.h with insertion points
   - Other templates for different output files

4. **Main Generator Script**:
   - `generate_command_code_new2.py`: Main script that orchestrates the generation process

## How It Works

1. The main generator script loads the JSON data files.
2. It reads the templates and identifies insertion points using markers like `{{generate_command_methods}}`.
3. For each insertion point, it calls the appropriate generation module with the JSON data.
4. The generation module processes the data and returns content to be inserted.
5. The generator substitutes the content into the template.
6. The completed files are written to the output location.

## Adding New Commands

To add a new command:

1. Add the command definition to `motor_commands.json` with:
   - `CommandString`: Human-readable name for the command
   - `CommandEnum`: Numeric ID for the command
   - `Description`: Detailed description of what the command does
   - `Input`: Array of input parameters (if any)
   - `Output`: Array of output parameters or "success_response"
   - `CommandGroup`: Logical grouping for the command

2. For each parameter, specify:
   - `Description`: String in format `"type: description"` (e.g., "u32: The maximum velocity")
   - `ParameterName`: Name to use in code for this parameter
   - `UnitConversion`: (Optional) For parameters that need unit conversion

3. For unit conversion, specify:
   ```json
   "UnitConversion": {
     "Type": "position",  // Type of unit (position, time, velocity, etc.)
     "InternalUnit": "encoder_counts",  // Unit used internally
     "ConversionFactorsFile": "unit_conversions_{motor_type}.json"
   }
   ```

4. For special complex parameter types like list_2d with mixed unit conversions, use:
   ```json
   "UnitConversion": {
     "Type": "mixed_acceleration_velocity_time",
     "InternalUnit": "mixed_acceleration_velocity_time",
     "ConversionFactorsFile": "unit_conversions_{motor_type}.json"
   }
   ```

## Generator Module Rules

When creating or modifying generator modules, always follow these rules:

### 1. NO HARDCODED COMMAND NAMES OR MAPPINGS

```python
# WRONG - DO NOT DO THIS:
function_name_mappings = {
    'Disable MOSFETs': 'disableMosfets',
    'Enable MOSFETs': 'enableMosfets',
    'Get n queued items': 'getNumberOfQueuedItems',
    'Get position': 'getPosition',
    'Get status': 'getStatus',
    'System reset': 'systemReset',
    'Set PID constants': 'setPIDConstants',
    'Multi move': 'multiMove',
}
```

This approach is brittle, requires updating the mapping whenever a new command is added, and won't work for new projects with different commands.

### 2. NO SPECIAL CASE HANDLING FOR SPECIFIC COMMANDS

```python
# WRONG - DO NOT DO THIS:
if cmd_str == "Multimove":
    # Special handling for Multimove
    list_type_name = "multiMoveList_t"
    converted_list_type = "multiMoveListConverted_t"
```

Special case handling is a maintenance nightmare and won't work for new projects.

### 3. USE CONSISTENT ALGORITHMIC APPROACHES

```python
# CORRECT APPROACH:
def format_command_name(command_string):
    command_string = command_string.strip()
    command_string = re.sub(r'[^a-zA-Z0-9]+', ' ', command_string)
    words = command_string.split()
    if not words:
        return ''
    
    # First word lowercase, rest capitalized
    return words[0].lower() + ''.join(w.capitalize() for w in words[1:])
```

This algorithm consistently transforms command strings to camelCase function names.

### 4. DETECT PATTERNS IN THE DATA

```python
# CORRECT APPROACH:
for param in cmd.get('Input', []):
    if param.get('UnitConversion'):
        needs_unit_conversion = True
        if param.get('UnitConversion', {}).get('Type') == 'mixed_acceleration_velocity_time':
            has_mixed_conversion = True
```

Use the data itself to determine behavior, not hardcoded command names.

### 5. USE TYPE-BASED PROCESSING

```python
# CORRECT APPROACH:
if type_str == 'list_2d' or param.get('UnitConversion', {}).get('Type') == 'mixed_acceleration_velocity_time':
    # Generate list type name from command name
    list_type_name = format_list_type_name(cmd_str)
    converted_list_type = format_list_type_name(cmd_str, converted=True)
```

Process based on parameter types and attributes, not command names.

## Common Mistakes to Avoid

1. **Hardcoding Response Structure Names**: Don't hardcode `getComprehensivePositionResponseConverted` - derive it algorithmically from the command name.

2. **Hardcoding List Type Names**: Don't hardcode `multiMoveList_t` - derive it algorithmically from the command name.

3. **Hardcoding Special Command Processing**: Don't add special cases for commands like `Multimove` - detect patterns in the data instead.

4. **Embedding Command-Specific Structures in Templates**: Don't embed structures like `multiMoveList_t` directly in templates - generate all structures from data.

By following these principles, the code generation system will remain flexible, maintainable, and able to handle any commands added in the future without requiring modifications to the generator code itself.

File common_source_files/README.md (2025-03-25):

# Servo Motor RS485 Communication Protocol

## Overview

This document describes the RS485-based communication protocol used in the servo motor control system. The protocol enables reliable communication between a host controller and multiple servo motor devices on a shared RS485 bus.

## Protocol Structure

### Packet Format

Each command packet follows this structure:

1. **Size Bytes**:
   - **Byte 1**: Encoded first byte containing the packet size
     - The LSB (bit 0) is always set to 1 for validation purposes
     - The actual size value is stored in bits 1-7 (size = encoded_byte >> 1)
     - If the decoded size value is 127 (DECODED_FIRST_BYTE_EXTENDED_SIZE), then the next two bytes form a 16-bit size value
     - Otherwise, this is the direct size of the entire packet including all fields
   
2. **Address Bytes**:
   - **Standard Addressing**: Single byte containing device alias
     - `255` (ALL_ALIAS): Broadcasts to all devices on the bus
     - `254` (EXTENDED_ADDRESSING): Indicates extended addressing mode
     - `253` (RESPONSE_CHARACTER): Indicates a response from a device
     - `0-252`: Normal device aliases
   - **Extended Addressing**: When the address byte is `254` (EXTENDED_ADDRESSING), the next 8 bytes contain the 64-bit Unique ID of the target device

3. **Command Byte**: 8-bit value specifying the operation to be performed

4. **Payload Data**: Variable length data according to the command requirements

5. **CRC32 (4 bytes)**: When CRC32 is enabled, the last 4 bytes of the packet contain a CRC32 checksum of all preceding bytes (including size and address bytes)

### Response Format

Responses from devices follow a similar format but always begin with the address byte set to `RESPONSE_CHARACTER` (253) to indicate a reply from a device.

## Command Processing Flow

1. **Initialization**: 
   - The system initializes UART1 for RS485 communication at 230400 baud
   - Hardware flow control is enabled using the DE pin for direction control (transmit/receive switching)

2. **Reception Process**:
   - When data arrives, the USART1 interrupt handler processes it byte by byte
   - Bytes are collected until a complete packet is formed based on the size information
   - Timeout detection resets the reception process if there's a gap in transmission
   - Error detection for framing, overrun, and noise errors

3. **Packet Validation**:
   - Validates that the first byte has LSB=1 (part of the encoding scheme)
   - Decodes the first byte to determine packet size
   - If extended size is indicated, reads the next two bytes for the full packet size
   - Checks if the packet is addressed to this device (matching alias, broadcast, or matching Unique ID)
   - If CRC32 is enabled, validates the CRC32 checksum
   - Buffers the packet for processing if valid

4. **Command Processing**:
   - Main program loop processes commands when `rs485_has_a_packet()` returns true
   - `rs485_get_next_packet()` extracts command, payload size, payload pointer, and broadcast flag
   - This function handles all addressing modes and returns only packets addressed to this device
   - After processing, `rs485_done_with_this_packet()` must be called to clear the receive buffer

5. **Response Transmission**:
   - `rs485_transmit()` sends basic data back to the host
   - `rs485_finalize_and_transmit_packet()` handles CRC32 calculation and packet finalization before transmission
   - Responses include the CRC32 checksum if CRC32 is enabled

## CRC32 Implementation

The protocol includes CRC32 error detection:

1. **Calculation**:
   - Uses hardware CRC32 unit for efficient processing
   - Calculated over the entire packet (including size and address bytes)
   - 4-byte CRC32 value appended to the end of the packet

2. **Control**:
   - Enabled by default after reset or power cycle
   - Can be disabled/enabled using `CRC32_CONTROL_COMMAND`
   - Error statistics tracked and retrievable via `GET_CRC32_ERROR_COUNT_COMMAND`

3. **Key Functions**:
   - `crc32_init()`: Initializes the CRC32 hardware unit
   - `calculate_crc32_buffer()`: Calculates CRC32 for a data buffer
   - `rs485_validate_packet_crc32()`: Validates received packet CRC32
   - `rs485_finalize_and_transmit_packet()`: Adds CRC32 to outgoing packets if enabled

## Error Handling

The protocol includes robust error handling mechanisms:

- **Framing errors**: Incorrect stop/start bits
- **Overrun errors**: Data received before previous byte processed
- **Noise errors**: Electrical interference
- **Command overflow**: New command received before previous one processed
- **Command too long**: Exceeding buffer capacity
- **CRC32 errors**: Data corruption during transmission

## Visual Indicators

- The red LED is turned on when bytes are being received and off when reception is idle

## Special Features

- **Timeout detection**: Resets the reception state if transmission is interrupted
- **Broadcast support**: Commands can be sent to all devices simultaneously
- **Hardware flow control**: Automatic direction switching for transmit/receive
- **Simulation support**: Protocol can be used in both real hardware and simulation environments

## Key Functions

- `rs485_init()`: Initializes the RS485 communication interface
- `rs485_has_a_packet()`: Checks if a valid packet is available for processing
- `rs485_get_next_packet()`: Retrieves the next packet for processing
- `rs485_validate_packet_crc32()`: Validates the CRC32 checksum of a packet
- `rs485_done_with_this_packet()`: Clears processed packet and enables reception of the next packet
- `rs485_transmit()`: Sends raw data over the RS485 bus without modification
- `rs485_finalize_and_transmit_packet()`: Sets packet size, adds CRC32 if enabled, and transmits the packet
- `encode_first_byte()`: Encodes a byte by shifting left and setting LSB to 1
- `decode_first_byte()`: Decodes a byte by shifting right

## Protocol Bit Structure

1. **First Byte Encoding**:
   - The least significant bit (LSB) of the first byte is always set to 1
   - This enables future automatic baud rate detection by ensuring a predicatble first low pulse

2. **Validation**:
   - The system validates that the first byte of a packet has LSB=1
   - Any packet with LSB=0 in the first byte is rejected
   - Reception resets after a timeout (10ms without UART traffic)

## Extended Addressing

The protocol supports addressing devices by their 64-bit Unique ID:

1. **Addressing Mode**:
   - When address byte is `EXTENDED_ADDRESSING (254)`, the next 8 bytes contain the device's 64-bit Unique ID

2. **Implementation Details**:
   - Firmware recognizes and processes extended addressing commands
   - Python library supports both standard addressing (by alias) and extended addressing (by Unique ID)
   - The `-a` option in the command-line interface accepts both aliases and Unique IDs (16-character hex strings)
   - The system automatically detects whether to use standard or extended addressing based on the input format

3. **Usage Example**:
   - Standard addressing: `python3 motor_command.py -a 1 ENABLE_MOSFETS`
   - Extended addressing: `python3 motor_command.py -a 0123456789ABCDEF ENABLE_MOSFETS`

## CRC32-Related Commands

1. **CRC32_CONTROL_COMMAND**:
   - Enables or disables CRC32 checking
   - Payload: Single byte (CRC32_ENABLE or CRC32_DISABLE)
   - Default: Enabled after reset or power cycle

2. **GET_CRC32_ERROR_COUNT_COMMAND**:
   - Retrieves the current CRC32 error count
   - Payload: Single byte (CRC32_ERROR_READ_ONLY or CRC32_ERROR_RESET)
   - Response: 32-bit error count
   - Can optionally reset the error counter

## Future Enhancements

Planned enhancements for the communication protocol:

1. **Support extended addressing in the Arduino module**
   - Enable specifying the unique ID when creating a motor object
   - Add function to change the unique ID of the class that is commanding the device

2. **Change the way that we set the alias**
   - Use extended addressing mode to address devices specifically
   - Simplify the "Set device alias" command to require only the new alias parameter

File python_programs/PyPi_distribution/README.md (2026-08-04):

## Usage

Here's a basic example of how to use the servomotor package:

TODO

For more detailed usage instructions, please refer to the documentation.

## Choosing the serial port

The command line tools work out which serial port to use in this order, highest
priority first:

1. `-p PORT` on the command line (`-P` instead pops up a menu of detected ports)
2. the `SERVOMOTOR_PORT` environment variable
3. the port saved from the last successful run
4. an interactive menu, if none of the above apply

So a port can be set once for a whole shell session:

```bash
export SERVOMOTOR_PORT=/dev/ttyUSB0        # Linux
export SERVOMOTOR_PORT=/dev/cu.usbserial-110   # macOS
set SERVOMOTOR_PORT=COM3                   # Windows (cmd)
$env:SERVOMOTOR_PORT = "COM3"              # Windows (PowerShell)
```

`-p` still overrides it for a single command, and `-P` always shows the menu.

After a port is opened successfully it is remembered, in a per-user location:

| Platform | Saved port file |
|---|---|
| Linux | `$XDG_CONFIG_HOME/servomotor/serial_device.txt`, else `~/.config/servomotor/serial_device.txt` |
| macOS | `~/Library/Application Support/servomotor/serial_device.txt` |
| Windows  | `%LOCALAPPDATA%\servomotor\serial_device.txt` |

Delete that file to forget the remembered port.

### Serial port permissions on Linux

Serial devices usually belong to the `dialout` group (`uucp` on some
distributions). If you get a permission error, add yourself to it:

```bash
sudo usermod -a -G dialout $USER
```

then log out and back in for the change to take effect.

## Features

- Control Gearotons servomotors via serial communication
- Easy-to-use interface for sending commands and receiving responses
- Automatic handling of serial port selection and management

## Requirements

- Python 3.6+

That is the whole list. pyserial is BUNDLED inside this package
(`servomotor/vendor/serial/`) and imported from there, so `pip install servomotor`
pulls in no other dependencies and you do not need to install pyserial yourself.

## Contributing

Contributions are welcome! Please feel free to submit a Pull Request.

## License

This project is licensed under the MIT License - see the [LICENSE](LICENSE) file for details.

## Contact

Tom Rodinger - tom.rodinger@alumni.utoronto.ca

Project Link: [https://gearotons.com](https://gearotons.com)

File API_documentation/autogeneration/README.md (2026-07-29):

# Servomotor API Documentation Generator

## Overview
This project generates comprehensive API documentation for both the Servomotor Python library and Arduino library. The documentation is auto-generated from the `motor_commands.json` file and produces both PDF and Markdown outputs for each library.

## Features
- **Auto-generated Documentation**: Reads command definitions from `motor_commands.json` and data type definitions from `data_types.json`
- **Multi-Library Support**: Generates separate documentation for both Python and Arduino libraries
- **Getting Started Section**:
  - Python: Includes complete example program from `python_library_example.py`
  - Arduino: Includes complete example program from `arduino_library_example.cpp` demonstrating trapezoid move
- **Data Types Section**: Comprehensive documentation of all data types used in the API, including:
  - Integer data types (i8, i16, i32, u8, u16, u32, u48, etc.) with size and range information
  - Special data types (strings, buffers, version numbers, CRC, etc.)
- **Error Handling Documentation**: Comprehensive error handling information section explaining how the servomotor handles errors
- **Error Codes Reference**: Complete listing of all error codes with:
  - Error code number and enum name
  - Short and detailed descriptions
  - Possible causes
  - Recommended solutions
- **Command Validation**: Ensures all commands have categories defined before generating documentation
- **Validation Error Handling**: Prominent error display if any command lacks a category, with instructions on how to fix
- **Code Examples**: Provides Python code examples for each motor command
- **Dual Output Formats**:
  - PDF for printable/shareable documentation
  - Markdown for AI-friendly and version-control friendly documentation
- **Command Grouping**: Organizes commands by category (Basic Control, Motion Control, Status & Monitoring, etc.)
- **Unit Conversion Support**: Documents available unit options for position, velocity, acceleration, etc.
- **Enhanced Styling**:
  - Command names displayed in green color matching the version/date header
  - Table of contents items in black, bold, and larger font for better readability
  - Section headings in black, bold, and larger font (18pt) for clear hierarchy

## Usage

### Generate Documentation
```bash
python M17_generate_api_documentation.py
```

This will generate the following files in the parent directory (../):
- `M17_servomotor_Python_API_documentation.pdf` - Python PDF documentation
- `M17_servomotor_Python_API_documentation.md` - Python Markdown documentation
- `M17_servomotor_Arduino_API_documentation.pdf` - Arduino PDF documentation
- `M17_servomotor_Arduino_API_documentation.md` - Arduino Markdown documentation

## Configuration Files

The generator uses several input files:
- `motor_commands.json` - Motor command definitions
- `data_types.json` - Data type definitions
- `error_codes.json` - Error code definitions with causes and solutions
- `error_handling.txt` - Error handling description text
- `hardware_setup.md` - Wiring, LEDs, buttons, mechanical/environmental (both documents)
- `knowhow.md` - Cross-cutting operational knowledge and gotchas (both documents)
- `arduino_essentials.md` - Error checking and Arduino environment setup (Arduino document only)

## Editing the documentation

**The `.md` and `.pdf` files in the parent directory are BUILD OUTPUTS. Never edit them —
the next run of the generator silently overwrites your changes.** Edit the source instead:

| To change | Edit |
|---|---|
| Per-command descriptions, parameters, returns | `../../python_programs/servomotor/motor_commands.json` |
| Error code causes and solutions | `../../python_programs/servomotor/error_codes.json` |
| Cross-cutting know-how, golden rules, gotchas | `knowhow.md` |
| Arduino error checking / environment setup | `arduino_essentials.md` |
| Hardware, wiring, LEDs | `hardware_setup.md` |
| Fatal-error concept text | `error_handling.txt` |
| The canonical Arduino example | `../../Arduino_library/example_trapezoid_move.cpp` (symlinked here) |
| The canonical Python example | `../../python_programs/example_trapezoid_move.py` (symlinked here) |
| Document structure, section order, what gets included | `M17_generate_api_documentation.py` |

Regenerate afterwards and diff both outputs.

### One know-how source, two languages

`knowhow.md` is rendered into BOTH documents so the two can never drift apart. Two
mechanisms adapt it to the reader's language, both implemented in
`render_shared_section()`:

1. **Language blocks**, for content that genuinely differs between the two libraries
   (program skeletons, exception handling versus `getError()`, return-value shapes):

   ```
   <!--LANG:PYTHON-->
   ...only in the Python document...
   <!--LANG:END-->
   <!--LANG:ARDUINO-->
   ...only in the Arduino document...
   <!--LANG:END-->
   ```

   These are HTML comments, so `knowhow.md` still reads correctly on its own. Blocks
   must not be nested, and every one must be closed.

2. **A curated symbol table**, `ARDUINO_API_SUBSTITUTIONS`, for prose that is identical
   apart from the spelling of a method name (`zero_position()` -> `zeroPosition()`).
   Every entry must be a symbol that actually exists in `Arduino_library/Servomotor.h`.
   When adding a Python method name to the shared prose, either add it to that table or
   use the command name in quotes (`'Zero position'`), which needs no translation.

After editing, check that nothing leaked across:

```bash
python3 M17_generate_api_documentation.py
cd ..
grep -c 'LANG:' M17_servomotor_*_API_documentation.md          # must be 0
grep -c 'get_status\|zero_position\|M3(' M17_servomotor_Arduino_API_documentation.md
grep -c 'getError\|Serial1' M17_servomotor_Python_API_documentation.md
```

### Markdown supported in the embedded sections

`add_markdown_section_to_pdf()` renders a subset of markdown into the PDFs: headings
(`#`/`##`/`###`), paragraphs, bullets, numbered lists, block quotes, fenced code blocks,
pipe tables, and inline `**bold**` and `` `code` ``. Anything outside that subset appears
verbatim in the PDF, so stick to it in `knowhow.md`, `hardware_setup.md` and
`arduino_essentials.md`.

## Validation Error Handling
If any command in `motor_commands.json` is missing a `CommandGroup` field:
- The program will display a prominent error message
- List all commands that lack categories
- Provide instructions to fix the issue (add CommandGroup to motor_commands.json)
- Exit without generating documentation

## Requirements
- Python 3.x
- ReportLab (for PDF generation)
- Motor commands definition file at: `../../python_programs/servomotor/motor_commands.json`
- Data types definition file at: `../../python_programs/servomotor/data_types.json`
- Error codes definition file at: `../../python_programs/servomotor/error_codes.json`
- Error handling text file at: `error_handling.txt`

## Documentation Contents

### Python Library Documentation
The generated Python documentation includes:
1. **Getting Started Guide** - Complete working example from `python_library_example.py` showing how to initialize and control the motor
2. **Data Types Reference** - Comprehensive documentation of all data types used in the API
3. **Complete Command Reference** - All commands with descriptions and parameters
4. **Parameter Specifications** - Data types and units for all command parameters
5. **Return Value Documentation** - Output specifications for commands that return data
6. **Practical Code Examples** - Python snippets for each command showing variable usage and output
7. **Unit Conversion Information** - Available units for position, velocity, acceleration, etc.
8. **Command Grouping by Functionality** - Commands organized by categories for easy navigation
9. **Error Handling Guide** - Detailed explanation of how the servomotor handles error conditions
10. **Error Codes Reference** - Complete listing of all error codes with causes and solutions

### Arduino Library Documentation
The generated Arduino documentation includes:
1. **Getting Started Guide** - Complete working example from `arduino_library_example.cpp` demonstrating trapezoid move control
2. **Data Types Reference** - Comprehensive documentation of all data types used in the API (same as Python)
3. **Complete Command Reference** - All commands with descriptions and parameters
4. **Parameter Specifications** - Data types and units for all command parameters
5. **Return Value Documentation** - Output specifications for commands that return data as structures
6. **Practical Code Examples** - Arduino/C++ snippets for each command showing proper structure instantiation
7. **Command Grouping by Functionality** - Commands organized by categories for easy navigation
8. **Error Handling Guide** - Detailed explanation of how the servomotor handles error conditions
9. **Error Codes Reference** - Complete listing of all error codes

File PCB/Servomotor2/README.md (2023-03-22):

Here are the PCB design files for the Servomotor2 project organised by the version number of the PCB

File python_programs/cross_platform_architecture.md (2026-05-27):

# Cross-Platform Servomotor Library Architecture

## Overview
This document outlines the architecture for making the servomotor Python library compatible with both standard Python (Mac/PC/Raspberry Pi) and MicroPython (ESP32-S3) using a single unified codebase.

## Requirements
- **Full feature parity** across all platforms
- **Single codebase** with conditional imports and platform detection
- **ESP32-S3 Configuration**: TX=Pin(4), RX=Pin(5), baudrate=230400
- **Maintain existing API** for backward compatibility

## Architecture Components

### 1. Platform Detection Module (`servomotor/platform_detect.py`)
```python
import sys

def get_platform():
    """
    Detects the current platform
    Returns: 'micropython' | 'standard'
    """
    return 'micropython' if sys.implementation.name == 'micropython' else 'standard'

def is_micropython():
    return get_platform() == 'micropython'

def is_esp32():
    if is_micropython():
        try:
            import machine
            # Check for ESP32-specific attributes
            return hasattr(machine, 'Pin')
        except:
            return False
    return False
```

### 2. Serial Port Abstraction Layer (`servomotor/serial_abstraction.py`)

```python
class SerialPort:
    """Base class for serial port operations"""
    
    def __init__(self, port=None, baudrate=230400, timeout=0.1):
        raise NotImplementedError
    
    def write(self, data):
        raise NotImplementedError
    
    def read(self, size):
        raise NotImplementedError
    
    def read_until(self, terminator, size=None):
        raise NotImplementedError
    
    def reset_input_buffer(self):
        raise NotImplementedError
    
    def close(self):
        raise NotImplementedError
    
    @property
    def name(self):
        raise NotImplementedError

class StandardSerial(SerialPort):
    """Implementation for standard Python with pyserial"""
    
    def __init__(self, port=None, baudrate=230400, timeout=0.1):
        from .vendor import serial
        self.ser = serial.Serial(port, baudrate, timeout=timeout)
    
    def write(self, data):
        return self.ser.write(data)
    
    def read(self, size):
        return self.ser.read(size)
    
    # ... other methods delegate to self.ser

class MicroPythonSerial(SerialPort):
    """Implementation for MicroPython on ESP32-S3"""
    
    def __init__(self, port=None, baudrate=230400, timeout=0.1):
        from machine import UART, Pin
        # Default pins for ESP32-S3
        self.uart = UART(
            1,  # UART(1) is the secondary port
            baudrate=baudrate,
            bits=8,
            parity=None,
            stop=1,
            tx=Pin(4),
            rx=Pin(5),
            timeout=int(timeout * 1000)  # Convert to milliseconds
        )
        self.timeout = timeout
    
    def write(self, data):
        return self.uart.write(data)
    
    def read(self, size):
        data = self.uart.read(size)
        return data if data else b''
    
    # ... implement other methods

def create_serial_port(port=None, baudrate=230400, timeout=0.1):
    """Factory function to create appropriate serial port"""
    from .platform_detect import is_micropython
    
    if is_micropython():
        return MicroPythonSerial(port, baudrate, timeout)
    else:
        return StandardSerial(port, baudrate, timeout)
```

### 3. Cross-Platform Utilities (`servomotor/platform_utils.py`)

```python
def calculate_crc32(data):
    """Calculate CRC32 with fallback for MicroPython"""
    try:
        import zlib
        return zlib.crc32(data) & 0xffffffff
    except ImportError:
        # MicroPython fallback - implement CRC32 algorithm
        return micropython_crc32(data)

def micropython_crc32(data):
    """Pure Python CRC32 implementation for MicroPython"""
    # CRC32 polynomial and implementation
    crc = 0xffffffff
    for byte in data:
        crc ^= byte
        for _ in range(8):
            if crc & 1:
                crc = (crc >> 1) ^ 0xedb88320
            else:
                crc >>= 1
    return crc ^ 0xffffffff

def get_terminal_columns():
    """Get terminal width with MicroPython fallback"""
    try:
        import shutil
        return shutil.get_terminal_size().columns
    except (ImportError, AttributeError):
        return 80  # Default width for MicroPython

def safe_print(message, style=None):
    """Print with optional styling (disabled on MicroPython)"""
    from .platform_detect import is_micropython
    
    if is_micropython() or style is None:
        print(message)
    else:
        # Apply terminal formatting for standard Python
        from terminal_formatting import STYLE
        print(f"{style}{message}{STYLE['RESET']}")

def load_json_file(filepath):
    """Load JSON with platform-appropriate method"""
    from .platform_detect import is_micropython
    
    if is_micropython():
        # MicroPython: Use ujson
        import ujson as json
    else:
        import json
    
    with open(filepath, 'r') as f:
        return json.load(f)

def save_serial_device(device_name):
    """Save serial device name with platform handling"""
    from .platform_detect import is_micropython
    
    if is_micropython():
        # On MicroPython, don't save to file or use different location
        return
    else:
        # Standard implementation
        import os
        current_dir = os.path.dirname(os.path.realpath(__file__))
        device_file_path = os.path.join(current_dir, "serial_device.txt")
        with open(device_file_path, "w") as f:
            f.write(device_name)
```

### 4. Modified Communication Module Structure

Key changes to `servomotor/communication.py`:
- Replace `ser` global with abstracted serial port
- Use platform utilities for CRC32, printing, etc.
- Conditional imports based on platform

```python
# At the top of communication.py
from .platform_detect import is_micropython, get_platform
from .serial_abstraction import create_serial_port
from .platform_utils import calculate_crc32, safe_print, get_terminal_columns

# Replace direct serial usage
def open_serial_port(timeout=1.2):
    global ser
    if is_micropython():
        # MicroPython doesn't need port selection
        ser = create_serial_port(baudrate=230400, timeout=timeout)
    else:
        # Standard Python with port selection
        from . import serial_functions
        ser = serial_functions.open_serial_port(serial_port, 230400, timeout=timeout)
```

### 5. Modified Terminal Formatting

Create fallback formatting for MicroPython:

```python
# servomotor/terminal_format_wrapper.py
from .platform_detect import is_micropython

if is_micropython():
    # Simple implementations for MicroPython
    def format_error(msg):
        return f"ERROR: {msg}"
    
    def format_info(msg):
        return f"INFO: {msg}"
    
    def format_warning(msg):
        return f"WARNING: {msg}"
    
    def format_success(msg):
        return f"SUCCESS: {msg}"
    
    def format_debug(msg):
        return f"DEBUG: {msg}"
    
    STYLE = {}
else:
    # Import from existing terminal_formatting module
    import sys
    import os
    sys.path.append(os.path.dirname(os.path.dirname(os.path.abspath(__file__))))
    from terminal_formatting import (
        format_error, format_info, format_warning, 
        format_success, format_debug, STYLE
    )
```

### 6. Ball Juggling Demo Adaptation

Key modifications for `ball_juggling_demo.py`:
- Conditional imports
- Platform-specific initialization
- Simplified file I/O for MicroPython

```python
#!/usr/bin/env python3

import sys
import time
import math

# Platform detection
try:
    import servomotor
    PLATFORM = 'standard'
except ImportError:
    # On MicroPython, the module might be in a different location
    sys.path.append('/flash')  # Or wherever the library is stored
    import servomotor
    PLATFORM = 'micropython'

# Platform-specific imports
if PLATFORM == 'micropython':
    import random
    # MicroPython doesn't have os module in the same way
    OUTPUT_LOG_FILE_DIRECTORY = None
else:
    import os
    import random
    OUTPUT_LOG_FILE_DIRECTORY = "./logs/"

# ... rest of the constants ...

# Main code with platform adaptations
if PLATFORM == 'standard' and OUTPUT_LOG_FILE_DIRECTORY:
    # File logging only on standard Python
    if not os.path.exists(OUTPUT_LOG_FILE_DIRECTORY):
        try:
            os.makedirs(OUTPUT_LOG_FILE_DIRECTORY)
        except OSError as e:
            print(f"Could not create log directory: {e}")
            OUTPUT_LOG_FILE_DIRECTORY = None

# Initialize servomotor
servomotor.open_serial_port()

# ... rest of the demo code ...
```

## Implementation Strategy

### Phase 1: Core Infrastructure
1. Create platform detection module
2. Implement serial port abstraction layer
3. Create platform utilities for CRC32, file I/O, terminal operations

### Phase 2: Library Refactoring
1. Update `communication.py` to use abstractions
2. Modify `serial_functions.py` for conditional execution
3. Update import statements throughout the library
4. Handle terminal formatting with fallbacks

### Phase 3: Testing and Validation
1. Deploy to ESP32-S3 and test basic communication
2. Test on Mac/PC with existing hardware to make sure nothing got broken
3. Run full ball_juggling_demo.py on both platforms
4. Debug and fix platform-specific issues

### Phase 4: Documentation
1. Installation instructions for MicroPython
2. Platform-specific configuration guide
3. API documentation with platform notes
4. Troubleshooting guide

## Testing Matrix

| Feature | Mac/PC | Raspberry Pi | ESP32-S3 |
|---|---|---|---|
| Serial Communication | ✓ | ✓ | ✓ |
| CRC32 Validation | ✓ | ✓ | ✓ |
| Command Execution | ✓ | ✓ | ✓ |
| Error Handling | ✓ | ✓ | ✓ |
| File Logging | ✓ | ✓ | ✗ |
| Port Selection Menu | ✓ | ✓ | ✗ |
| Terminal Formatting | ✓ | ✓ | Simple |
| Ball Juggling Demo | ✓ | ✓ | ✓ |

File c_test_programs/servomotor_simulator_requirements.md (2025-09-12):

# Servomotor Simulator Requirements

## Overview
The goal is to create a comprehensive simulator for a servomotor that:
1. Uses actual motor firmware code for accurate behavior
2. Emulates STM32G031 hardware features
3. Provides a simulated serial port interface
4. Shows real-time visualization of motor movement

## Current Status

### Implemented and Tested
- RS485 command processing:
  - USART1 peripheral configured for interrupt-driven reception
  - Command validation for both device alias (0x01) and broadcast (0xFF)
  - Debug logging tracks command flow
  - Successfully tested commands:
    - "Enable MOSFETs" with temperature checks
    - "Disable MOSFETs"
    - "Trapezoid move" with position tracking
    - "Set maximum velocity" with velocity value
    - "Detect devices" with random delay (0-990ms)
      * Random delay working correctly
      * Unique ID transmission verified
      * CRC32 calculation confirmed accurate
  - Command responses working:
    - Non-broadcast commands get proper responses
    - Response format verified (RESPONSE_CHAR, payload flag, length, data)
    - Hardware FIFO behavior correctly emulated
- System timing:
  - SysTick simulation running at precise 100Hz
  - Dedicated thread using spinlock timing
  - Frequency verified through profiling output
  - Successfully handles command delays and timeouts
- Motor control:
  - MOSFET state changes update visualization
  - Position tracking and visualization working
- System setup:
  - Basic motor visualization using SDL
  - Simulated serial port creation (/dev/ttysxxx)
  - Command reception through serial port
- Movement commands:
  - "Go to position":
    * Successfully tested with position=1000000, duration=31250
    * Command processed correctly
    * Motor visualization shows smooth movement
    * Proper response received
    * Note: Smaller position values (e.g. 1000) produce minimal visible movement
  - "Move with velocity":
    * Tested with velocity=1000000, duration=31250
    * Command processed correctly with stable timing
    * Timer maintains 31.25 kHz with <100μs deviation
    * Movement visible but slow - needs higher velocity value
    * Motor stops correctly when followed by velocity=0 command
  - "Move with acceleration":
    * Tested with acceleration=400000, duration=31250
    * Followed by deceleration=-400000, duration=31250
    * Command processed correctly
    * Smooth acceleration and deceleration
    * Motor stops correctly at zero velocity
  - "Get comprehensive position":
    * Tested after Go to position command (target: 1000000)
    * Command processed correctly
    * Response format verified:
      - Commanded position: 999999 (matches target)
      - Hall sensor position: 0 (needs simulator update)
      - External encoder: 0 (as expected, no hardware attached)
    * Note: Hall sensor position should track commanded position in simulator

### Fixed Issues
- Receive interrupt not re-enabled after command processing:
  - Issue: Commands were received and validated correctly, but subsequent commands were dropped
  - Fix: Verified rs485_done_with_this_packet() is called at the start of each command case in process_packet()
  - Result: Multiple commands can now be processed in sequence
- MOSFET Control:
  - Issue: "Enable MOSFETs" command triggered overheat error immediately after enabling
  - Investigation: get_temperature_ADC_value() was returning 0, below overheat threshold
  - Fix: Updated get_temperature_ADC_value() to return safe temperature value (16000)
  - Result: MOSFETs can now be enabled and disabled properly, visualization updates correctly
- USART Transmit Blocking:
  - Issue: Transmit operations were blocked by read loop, causing data loss
  - Investigation: Found transmit handling in read thread was blocking on read()
  - Fix: Split read and write operations into separate threads
  - Result: Commands and responses now transmit reliably without blocking

- Timer Performance:
  - Issue: TIM16_IRQHandler frequency was unstable during motor movement
  - Investigation: Found timing affected by visualization and debug logging
  - Fix: Moved motor control to dedicated thread with spinlock timing
  - Result: Stable 31.25 kHz with <100μs deviation

- High CPU Usage:
  - Issue: Simulator was consuming excessive CPU resources
  - Impact:
    * System performance degradation
    * Rapid battery drain on laptops
    * Non-smooth motor movement visualization
  - Fix:
    * Optimized spinlock timing in motor control thread
    * Adjusted SDL rendering frequency
    * Improved thread synchronization
  - Result: Simulator now runs efficiently with minimal CPU usage while maintaining accurate timing

- Static Variable Initialization:
  - Issue: Static variables in multiple modules were not properly reset between simulation runs
  - Impact:
    * Stale variable values could affect subsequent simulation runs
    * Inconsistent behavior between runs
    * Reset functionality not working correctly
  - Fix:
    * Implemented initialization functions for three key modules:
      - error_handling_simulator_init() for error handling module
      - motor_control_simulator_init() for motor control module
      - RS485_simulator_init() for RS485 communication module
    * Moved static variables from function scope to module scope where needed
    * Centralized reset logic in reset_all_modules() function
  - Result: All modules are now properly reset between simulation runs, ensuring consistent behavior

- MOSFET State After Reset:
  - Issue: MOSFETs remained enabled after "System reset" command
  - Investigation: Found GPIO IDR state not tracking BSRR changes in simulation
  - Fix:
    * Changed is_mosfets_enabled() to read GPIO state directly
    * Added GPIO state tracking in motor control thread (31.25kHz)
    * IDR registers now properly track BSRR changes
  - Result: MOSFETs correctly disabled after system reset

- "Set device alias" Command:
  - Issue: Motor stopped responding after "Set device alias" command
  - Investigation: Found microsecond_delay() not implemented in simulation
  - Fix:
    * Created microsecond_clock_sim.c for simulation timing
    * Implemented accurate microsecond timing using CLOCK_MONOTONIC
    * Added proper GPIO state tracking for visualization
  - Result: Device alias successfully changes and persists across resets

### Current Focus
- No current focus items - all planned features implemented

### Known Issues
- Motor Movement When Disabled:
  - Issue: Motor visualization continues to move even when MOSFETs are disabled
  - Expected: Real motor cannot move with disabled MOSFETs
  - Impact: Simulator behavior differs from real hardware
  - Status: To be fixed in future update

### Implementation Mistakes
- Attempted to implement TIM16_IRQHandler() when it already exists in motor_control.c:
  - Mistakenly thought the function was missing because we couldn't see its implementation
  - Important lesson: Don't assume a function needs to be implemented just because you can't find it
  - Always check all source files thoroughly before attempting to implement a function
- Over-complicated timing logic:
  - Added unnecessary checks for elapsed time after nanosleep()
  - Added complex signal handling for nanosleep()
  - Important lesson: Keep it simple - nanosleep() is sufficient for timing
- Wasted time editing obsolete function:
  - Tried to modify handle_firmware_command() in servo_simulator.c
  - This function is obsolete as commands are now handled in main.c's process_packet()
  - Important lesson: Always check if code is still in use before modifying it
  - When fixing issues, first verify the code path is actually being used
- Failed to mark debug prints with "// DEBUG" comment:
  - Added debug prints to error_handling.c without proper "// DEBUG - temporarily added to aid in debugging" marker
  - Made another mistake by not marking variable assignments used only for debugging
  - Important lesson: Every line added for debugging must have "// DEBUG - temporarily added to aid in debugging"
  - This includes variable assignments, not just print statements
  - This helps track which code was added for debugging purposes and should be removed later

- Incorrectly documented fixed issues:
  - Wrote about solved timer performance issue in Known Issues section
  - Fixed issues should be removed from Known Issues and added to Fixed Issues
  - Important lesson: Documentation organization matters - keep issues in their proper sections
  - Known Issues is only for current, unresolved issues
  - When an issue is fixed, move it from Known Issues to Fixed Issues

- Attempted to delete previous test results:
  - When adding new test results, tried to delete older test results
  - Important lesson: Never delete test results
  - All test results are valuable documentation of what was tested
  - Keep all test results as a record of implementation progress

### Implementation Details
- Device addressing:
  - Device alias (0x01) loaded from non-volatile memory at startup
  - Commands must match device alias or ALL_ALIAS (0xFF)
  - Command validation in RS485.c checks:
    ```c
    if(selectedAxis != RESPONSE_CHARACTER && (selectedAxis == global_settings.my_alias || selectedAxis == 255))
    ```

- CRC32 calculation:
  - Implemented in settings_sim.c to match hardware behavior
  - Used for "Detect devices" command response validation
  - Calculates CRC32 over:
    * 8-byte unique ID
    * 1-byte device alias
  - Matches hardware CRC32 peripheral behavior:
    * Uses standard CRC32 polynomial (0xEDB88320)
    * Final value is inverted (~CRC32)

- Movement Commands:
  - "Go to position": 
    * Single command that handles acceleration/deceleration automatically
    * Example with position verification:
      ```bash
      ./servomotor_command.py -a 01 -p /dev/ttys123 "Enable MOSFETs" ; \
      ./servomotor_command.py -a 01 -p /dev/ttys123 "Go to position" 1000000 31250 ; \
      sleep 2 ; ./servomotor_command.py -a 01 -p /dev/ttys123 "Get comprehensive position"
      ```
  - Compound Commands:
    * "Move with velocity": 
      - Must be used as a pair of commands with sleep:
        1. First command: Set desired velocity and duration
        2. Second command: Set velocity=0 with short duration
        3. Sleep longer than total movement time
      - Example: 
        ```bash
        ./servomotor_command.py -a 01 -p /dev/ttys123 "Move with velocity" 1000000 31250 ; \
        ./servomotor_command.py -a 01 -p /dev/ttys123 "Move with velocity" 0 1000 ; \
        sleep 2
        ```
      - Fatal error occurs if velocity not brought to 0
    * "Move with acceleration":
      - Must be used as a pair of commands with sleep:
        1. First command: Set positive acceleration for time T
        2. Second command: Set negative acceleration for time T
        3. Sleep longer than total movement time
      - Example:
        ```bash
        ./servomotor_command.py -a 01 -p /dev/ttys123 "Move with acceleration" 400000 31250 ; \
        ./servomotor_command.py -a 01 -p /dev/ttys123 "Move with acceleration" -400000 31250 ; \
        sleep 2
        ```
      - Ensures velocity returns to 0

### Protocol Details
- Command Format:
  1. Axis byte: 0x00 (AXIS_MOTOR) or 0xFF (AXIS_ALL)
  2. Command byte: Command identifier
  3. Length byte: Number of payload bytes (0 for no payload)
  4. Payload bytes (if any)
- Device Addressing:
  - Each device has a unique ID and an alias
  - "Set device alias" command can change a device's alias
  - Commands can target a specific alias or all devices (0xFF)

### To Do
1. Update simulator to track hall sensor position with commanded position

## Testing Process
For each feature implementation:
1. Verify project compiles successfully
2. Confirm program runs without crashes
3. Test commands using servomotor_command.py:
   ```bash
   ./servomotor_command.py -a <alias> -p <port> "<command name>" [parameters...]
   ```
   Example:
   ```bash
   ./servomotor_command.py -a 01 -p /dev/ttys123 "Set maximum velocity" 1000
   ```
4. Document test results and any issues found

Note: Always use servomotor_command.py to send commands rather than raw byte sequences. This ensures we use the correct command format and parameter encoding.

## Source Files
- servo_simulator.c: Main simulator implementation
- ../firmware/Src/main.c: Motor firmware main logic
- ../common_source_files/RS485.c: RS485 communication implementation
- Makefile: Project build configuration

## Implementation Notes
- Debug print statements should be marked with "// DEBUG - temporarily added to aid in debugging"
- RS485 command processing follows the actual firmware's interrupt-driven approach
- Commands are processed only when receive interrupt is enabled (RXNEIE)
- RXNE flag is properly managed to simulate hardware behavior

## Original Requirements Message
Currently I have a program that simulates a small subset of functionality of a servomotor. The program is called servo_simulator.c. I need to make a more comprehensive simulator that supports many more commands. I want to use most of the actual motor firmware code, so that the simulation is well representative of what the motor will actually do. I have built a suitable makefile already, which successfully compiles the project on my M1 Mac. Then, we will have to emulate some parts of the hardware of the STM32G031 chip to receive commands over a simulated serial port and also extract the movement information from the motor firmware and show a visualization of the motor spinning in an accurate way. The graphical visualization of the motor (spinning or stationary) is already working and is implemented in servo_simulator.c. Another part that is implemented is that a simulated serial port appears on the system as /dev/ttysxxx, where xxx is some number. If I send a command to that erial port, the bytes are received in the simulator and printed to the log window. From there, the command is not yet correctly received and interpretted by the firmware of the motor. 

The source code files to look at first are:
Makefile
servo_simulator.c
../firmware/Src/main.c
../common_source_files/RS485.c

Please look around at the various source code available here and then let's start working on letting the RS485 module receive bytes through the simulated serial port and interpretting them correctly. If you need to add print statements to the source code of the servomotor, such as in main.c or RS485.c then please always follow the print statements with // DEBUG - temporarily added to aid in debugging. later remove this line.

This is the documentation of the project as we work through it. Please always keep this file up to date at each iteration so that we know what all the requirements are and what is still left to do. This file should grow over time but be kept concide. You can use .md markup format if you want. I will be strictly policing this, that you update this file at each iteration. If you don't have any update then you can skip it if you let me know explicitly that there is not update at this time. If we find a major problem and we solve it then we should also document it here. If you make a major mistake and we need to backtrack a bit then we also need to add some documentation here to prevent us from making that same mistake. This message should remain in the documentation, but can be reworded if that simhow improves the messaging.

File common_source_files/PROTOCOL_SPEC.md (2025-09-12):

# Servo Motor RS485 Communication Protocol

## Overview

This document describes the RS485-based communication protocol used in the servo motor control system. The protocol enables reliable communication between a host controller and multiple servo motor devices on a shared RS485 bus.

## Protocol Structure

### Packet Format

Each command packet follows this structure:

1. **Size Byte(s)**:
   - **7-bit size**: Encoded first byte containing the packet size
     - The LSB (bit 0) is always set to 1 for validation purposes and to enable automatic baud rate detection in the future
     - The actual size value is stored in bits 1-7 (size = encoded_byte >> 1)
     - This is the direct size of the entire packet including all fields and even including the size byte, unless the decoded size is 127, which indicated extended size
   - **Extended 16-bit size**: Encoded first byte contains 127 and two more bytes contain the actual 16-bit size
     - If the decoded size value is 127 (DECODED_FIRST_BYTE_EXTENDED_SIZE), then the next two bytes form a 16-bit size value. It is little endian.
   
2. **Address Byte(s)**:
   - **Standard Addressing**: Single byte containing device alias
     - `255` (ALL_ALIAS): Broadcasts to all devices on the bus
     - `254` (EXTENDED_ADDRESSING): Indicates extended addressing mode
     - `253` (RESPONSE_CHARACTER_CRC32_ENABLED): Indicates a response from a device where the response HAS a 4-byte CRC32 checksum at the end
     - `252` (RESPONSE_CHARACTER_CRC32_DISABLED): Indicates a response from a device where the response DOES NOT HAVE a 4-byte CRC32 checksum at the end
     - `0-251`: Normal device aliases
   - **Extended Addressing**: When the address byte is `254` (EXTENDED_ADDRESSING), the next 8 bytes contain the 64-bit Unique ID of the target device

3. **Command Byte**: 8-bit value specifying the operation to be performed

4. **Payload Data**: Variable length data according to the command requirements

5. **CRC32 (4 bytes, optional)**: When CRC32 is enabled, the last 4 bytes of the packet contain a CRC32 checksum of all preceding bytes (including size and address bytes)

### Response Format

Responses from devices follow a similar format: they start with the size byte, and are followed by an address byte, which is set to eitiher `253` (RESPONSE_CHARACTER_CRC32_ENABLED) to indicate a reply from a device with a CRC32 checksum appended, or to `252` (RESPONSE_CHARACTER_CRC32_DISABLED) to indicate a reply from a device which does not have the 4-byte CRC32.

## Command Processing Flow

1. **Initialization**: 
   - The system initializes UART1 for RS485 communication at 230400 baud
   - Hardware is configured to use the hardware based communication direction control through the DE pin (transmit/receive switching)

2. **Reception Process**:
   - When data arrives, the USART1 interrupt handler processes it byte by byte
   - Bytes are collected until a complete packet is formed based on the size information
   - Timeout detection resets the reception process if there's a gap in transmission
   - Error detection for framing, overrun, and noise errors
   - Statistics are gathered for any of these arrors
   - These types of errors do not cause a fatal error and a command is available for the user to fetch the statistics from the device

3. **Packet Validation**:
   - Validates that the first byte has LSB=1 (part of the encoding scheme)
   - Decodes the first byte to determine packet size
   - If extended size is indicated, reads the next two bytes for the full packet size
   - Checks if the packet is addressed to this device (matching alias, broadcast, or matching Unique ID)
   - If CRC32 is enabled, validates the CRC32 checksum
   - Buffers the packet for processing if valid

4. **Command Processing**:
   - Main program loop processes commands when `rs485_has_a_packet()` returns true
   - `rs485_get_next_packet()` extracts command, payload size, payload pointer, and broadcast flag
   - This function handles all addressing modes and returns only packets addressed to this device
   - After processing, `rs485_done_with_this_packet()` must be called to clear the receive buffer

5. **Response Transmission**:
   - `rs485_transmit()` sends basic data back to the host
   - `rs485_finalize_and_transmit_packet()` handles CRC32 calculation and packet finalization before transmission
   - Responses include the CRC32 checksum if CRC32 is enabled

## CRC32 Implementation

The protocol includes CRC32 error detection:

1. **Calculation**:
   - Uses hardware CRC32 unit for efficient processing
   - Calculated over the entire packet (including size and address bytes)
   - 4-byte CRC32 value is placed at the very end of the packet in all cases

2. **CRC32 Enable or Disable Control**:
   - Enabled by default after reset or power cycle
   - Can be disabled/enabled using `CRC32_CONTROL_COMMAND`
   - CRC32 error statistics tracked and retrievable via `GET_CRC32_ERROR_COUNT_COMMAND`
   - A device will check or not check the CRC32 of a received packet based on whether or not the CRC32 checking is enabled through this command
   - A response will have or not have a CRC32 checksome appended based on whether or not the CRC32 checking is enabled through this command
   - User needs to be careful that if he/she disables CRC32 (not the default) then all commands following should have no CRC32 bytes and also the responses from the device will have no CRC32 calculated or appended
   - The main advantage of disabling CRC32 checking is that it makes communication a bit faster (less bytes to send). The user is advised that they should first try their application with CRC32 enabled and periodically look at the communication statistics to make sure that communication is happening with 100% reliablilty. Only then should they consider to disable CRC32 checking.

3. **Key Functions**:
   - `crc32_init()`: Initializes the CRC32 hardware unit
   - `calculate_crc32_buffer()`: Calculates CRC32 for a data buffer
   - `rs485_validate_packet_crc32()`: Validates received packet CRC32
   - `rs485_finalize_and_transmit_packet()`: Adds CRC32 to outgoing packets if enabled

## Error Handling

The protocol includes robust error handling mechanisms:

- **Framing errors**: Incorrect stop/start bits
- **Overrun errors**: Data received before previous byte processed
- **Noise errors**: Electrical interference
- **Command overflow**: New command received before previous one processed
- **Command too long**: Exceeding buffer capacity
- **CRC32 errors**: Data corruption during transmission or invalid packet format

## Visual Indicators

- The green LED is turned on when bytes are being received and off when reception is idle

## Special Features

- **Timeout detection**: Resets the reception state if transmission is interrupted
- **Broadcast support**: Commands can be sent to all devices simultaneously
- **Communication direction control**: Automatic direction switching for transmit/receive using DE pin of the hardware
- **Simulation support**: Protocol can be used in both real hardware and simulation environments

## Key Functions

- `rs485_init()`: Initializes the RS485 communication interface
- `rs485_has_a_packet()`: Checks if a valid packet is available for processing
- `rs485_get_next_packet()`: Retrieves the next packet for processing
- `rs485_validate_packet_crc32()`: Validates the CRC32 checksum of a packet
- `rs485_done_with_this_packet()`: Clears processed packet and enables reception of the next packet
- `rs485_transmit()`: Sends raw data over the RS485 bus without modification
- `rs485_finalize_and_transmit_packet()`: Sets packet size, adds CRC32 if enabled, and transmits the packet
- `encode_first_byte()`: Encodes a byte by shifting left and setting LSB to 1
- `decode_first_byte()`: Decodes a byte by shifting right

## Packet Validation
   - The system validates that the first byte of a packet has LSB=1
   - Any packet with LSB=0 in the first byte is rejected by attempting to receive it despite the error and then discarding the packet
   - Packets are also validated based on the CRC32 checksum that is at the end of every packet (although this can be disabled to save bytes)
   - Reception resets after a timeout (10ms without UART traffic), so one way to make sure that a corrupt packet gets flushed it to wait the timeout before sending another packet

## Extended Addressing

The protocol supports addressing devices by their 64-bit Unique ID:

1. **Addressing Mode**:
   - When address byte is `EXTENDED_ADDRESSING (254)`, the next 8 bytes contain the device's 64-bit Unique ID

2. **Implementation Details**:
   - Firmware recognizes and processes extended addressing commands
   - Python library supports both standard addressing (by alias) and extended addressing (by Unique ID)
   - The `-a` option in the command-line interface accepts both aliases and Unique IDs (16-character hex strings)
   - The system automatically detects whether to use standard or extended addressing based on the input format

3. **Usage Example**:
   - Standard addressing: `python3 servomotor_command.py -a 1 ENABLE_MOSFETS`
   - Extended addressing: `python3 servomotor_command.py -a 0123456789ABCDEF ENABLE_MOSFETS`

## CRC32-Related Commands

1. **CRC32_CONTROL_COMMAND**:
   - Enables or disables CRC32 checking
   - Payload: Single byte (CRC32_ENABLE or CRC32_DISABLE)
   - Default: Enabled after reset or power cycle

2. **Get communication statistics command**:
   - Retrieves the current CRC32 error count, packet decode error count, first bit error count, framing error count, overrun error count, and noise error count
   - Payload: Single byte (CRC32_ERROR_READ_ONLY or CRC32_ERROR_RESET)
   - Response: 32-bit numbers for each type of error
   - Can optionally reset the error counter after getting the counts
   - See the motor_commands.json file for more details or run `python3 servomotor_command.py -c`

## Future Enhancements

Planned enhancements for the communication protocol:

1. **Support extended addressing in the Arduino module**
   - Enable specifying the unique ID when creating a motor object
   - Add function to change the unique ID of the class that is commanding the device

2. **Change the way that we set the alias**
   - Use extended addressing mode to address devices specifically
   - Simplify the "Set device alias" command to require only the new alias parameter
   
3. **Automatic baud rate detection**
   - The first bit of the first byte of a packet is purposely always set to 1, which forces the start bit to be clearly define with a falling edge and a rising edge after one bit time. Theoretically we can calculate the baud rate from this.

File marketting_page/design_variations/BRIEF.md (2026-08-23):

# Gearotons M17 Marketing Page — Shared Content Brief

You are building ONE standalone marketing page variant (a single self-contained .html file).
This brief contains ALL the factual content. Do not invent specs, prices, or claims not listed here.

## Company / brand
- Company: **Gearotons** (young startup, founded in Shenzhen 2022 by a Canadian entrepreneur)
- Product: **M17 Series Servomotors** — all-in-one motion control
- Tagline currently used: "Affordable and Simple All-in-One Motion Control"
- Brand colors: green (≈ #7AB648, from the logo), black, white. (Variants may propose other palettes if the design direction says so.)
- Live site: https://gearotons.com — CTA buttons should link to https://gearotons.com/store
- Logo images (black gear + green robot arms, transparent/white background):
  - `../Gearotons_Logo.png` (logo mark only)
  - `../Gearotons_Logo_and_Gearotons_Name.png` (logo + wordmark, white background — only good on white)

## Available images (paths are relative to the design_variations/ directory where your HTML file lives)
All product photos are BLACK motors on WHITE/light backgrounds — on dark themes place them in light cards or accept the white background creatively.
- `../M17_series_overview.jpg` — the three motors side by side with model labels (good hero image, landscape)
- `../one_motor.jpg` — beautiful 3/4 studio shot of a single motor, white bg (large, portrait-ish)
- `../kit_with_three_motors.jpg` — full kit flat-lay: 3 motors, adapter PCB, cables, knobs (portrait)
- `../motor_back.jpg` — back of motor showing printed specs label + QR codes, Reset/Test buttons (portrait)
- `../adapter_and_wire.jpg` — green "3-in-1 RS485 Adapter" PCB with cable (landscape)
- `../automation.jpg` — motor mounted in an automation machine (application photo)
- `../robotics.jpg` — motor in a CNC/robotics metal assembly with large gear (application photo, square)
- `../test_rack.jpg` — motors in a testing rack (application photo)
- `../connection_diagram.jpg` — wiring diagram (white background, technical)
- `../preview/public/marketing/images/M17-40_dimensions.png`, `../preview/public/marketing/images/M17-48_dimensions.png`, `../preview/public/marketing/images/M17-60_dimensions.png` — CAD dimension drawings (white bg)
- `../Open_Source_Initiative.svg.png`, `../Open-source-hardware-logo.svg.png` — open source logos

## Intro copy (may be shortened/rephrased for marketing punch, keep facts)
The M17 Series Servomotors are all-in-one motion control solutions that integrate a motor, motor driver, motion controller, and encoder in a single compact package. RS-485 interface lets you daisy-chain any number of motors and control them from a single connection point. Three models — M17-60, M17-48, M17-40 — offer flexible torque options with consistent control characteristics.

Control from any platform: Mac, PC, Raspberry Pi, Arduino, ESP32 (needs only a low-cost RS485 adapter). Sophisticated control: multiple operation modes, self-calibration, LED status indicators, trapezoid movement profiles, closed-loop control, comprehensive error handling. Standard NEMA 17 mounting, 12–24V, robust protocol. Ideal for education AND industry: robotics, CNC, automated testing, scientific instruments.

## Key features (pick the best ones; you don't need all 16)
1. Motor + driver + motion controller + encoder integrated in one package
2. Control any number of motors over one RS-485 bus from one controller
3. High-level commands like "Enable MOSFETs" and "Trapezoid move" — no timing-critical STEP/DIR signals
4. Nearly the same size as a NEMA 17 stepper with the same specs (no protrusions)
5. Standard NEMA 17 mounting dimensions
6. Wide voltage range 12–24V
7. High-precision closed-loop control: built-in encoder + PID loop running at 32 kHz
8. Much more power efficient in closed loop vs. a conventional stepper
9. Integrated over-current, over-voltage, over-temperature protection
10. Max speed 560 RPM
11. Same torque-to-weight ratio as an equivalent stepper
12. Works with Raspberry Pi, Arduino, ESP32, Mac, PC
13. Excellent documentation and tutorials
14. AI-friendly documentation (let your favorite AI do the work)
15. Suitable for robotics, CNC, automation, scientific instruments, test jigs, 3D printers
16. Three sizes to match torque and budget

## Technical specifications (table)
| Parameter | M17-60 | M17-48 | M17-40 |
|---|---|---|---|
| Operating Voltage | 12–24V | 12–24V | 12–24V |
| Rated Torque | 0.65 N·m | 0.55 N·m | 0.42 N·m |
| Maximum Speed | 560 RPM | 560 RPM | 560 RPM |
| Maximum Current | 1.1 A | 1.1 A | 1.1 A |
| Rated Power | 38 W | 32 W | 25 W |
| Height | 59.8 mm | 48.6 mm | 41.6 mm |
| Footprint | 42.2 × 42.2 mm | 42.2 × 42.2 mm | 42.2 × 42.2 mm |
| Weight | 470 g | 360 g | 285 g |

## Python code example (for developer-oriented sections; Arduino also supported)
```python
import servomotor
from servomotor import M3

servomotor.open_serial_port()
motor = M3("X", time_unit="seconds",
                position_unit="degrees")
motor.system_reset()
motor.enable_mosfets()
motor.trapezoid_move(360, 2)  # one revolution in 2 s
```
Install: `pip3 install servomotor` · Arduino library available in the Library Manager ("Servomotor")
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

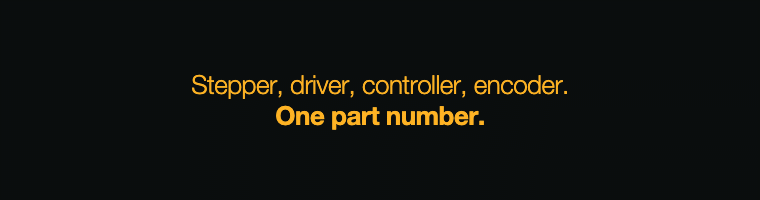
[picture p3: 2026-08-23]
marketting_page/slogan_lab/gifs/mechanical-dot-matrix.gif

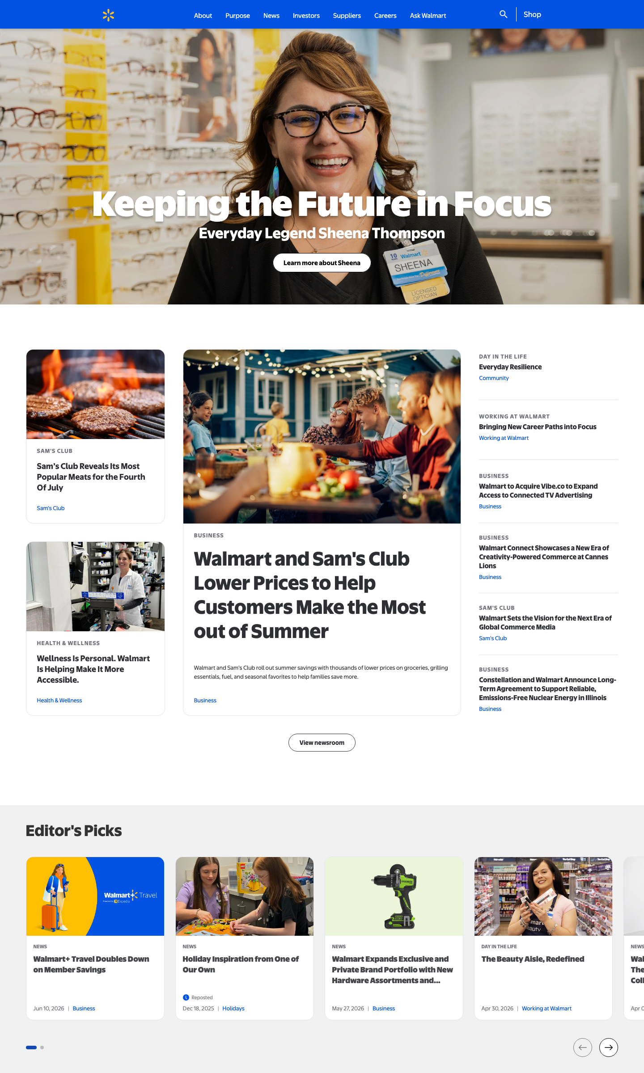
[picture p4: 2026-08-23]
marketting_page/design_variations/research/shots/19_walmart.png

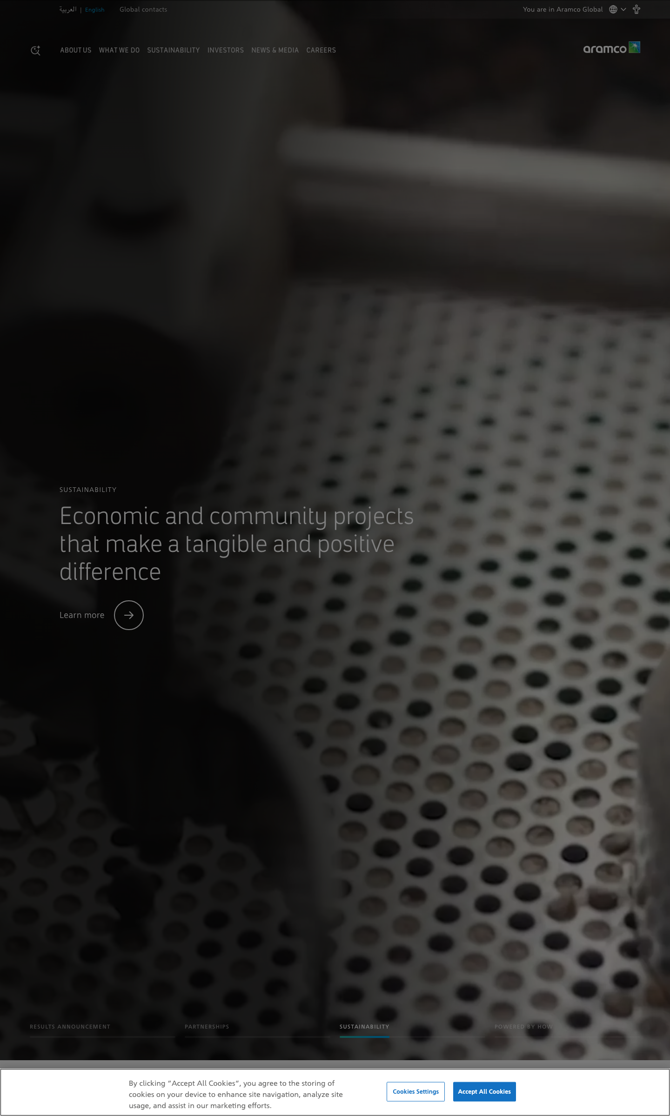
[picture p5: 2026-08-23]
marketting_page/design_variations/research/shots/9_saudi_aramco.png

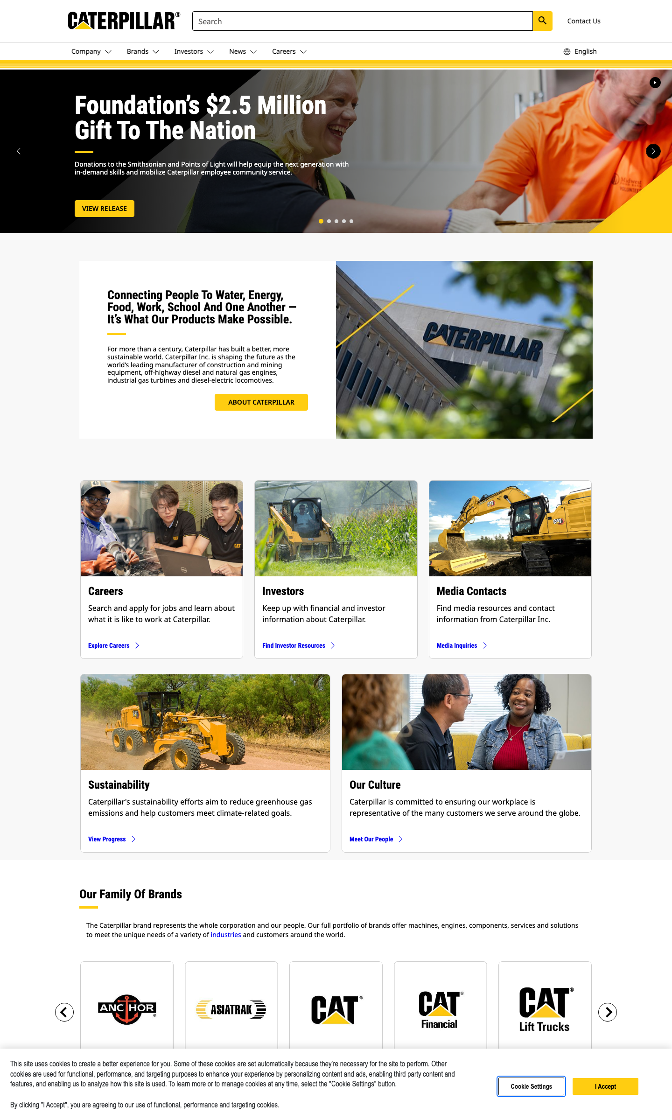
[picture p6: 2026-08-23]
marketting_page/design_variations/research/shots/30_caterpillar.png

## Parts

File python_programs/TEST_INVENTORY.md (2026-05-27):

# Test Inventory & Assessment

Snapshot of the test programs that exist today for exercising the motor, plus a
gap analysis. Purpose: decide what test coverage is needed before refactoring
the Python library for MicroPython compatibility.

---

## A. Python library tests (`python_programs/`)

### Runner
`run_all_tests.py` is the harness:
1. Parses `TEST_SUMMARY.md`, selects rows where **Module = `servomotor`** and
   **Obsolete = `No`**.
2. Explicitly skips `test_servomotor_module.py` and
   `test_servomotor_module_get_command_id.py`.
3. Runs each remaining test as a subprocess: `python3 <test> -p PORT -a ALIAS`.
4. Pass criteria: exit code 0 **and** the last stdout line contains `PASSED`.
5. Per-test timeout: 240 s. Exits non-zero if any test fails.

Invocation: `python3 run_all_tests.py -p /dev/ttyUSB0 -a X`
(or `-P` to pick the port interactively).

### Catalogue (`TEST_SUMMARY.md`): 32 test files total
- 16 use the modern `servomotor` library — 15 marked non-obsolete, 1 obsolete.
- 9 use the deprecated `communication` module — all obsolete.
- 1 uses raw `serial`.
- 6 are `N/A` (utilities / plotting / no motor).

### Auto-run suite (14 tests — ALL require connected hardware)
1. `test_ping.py` — ping round-trip, payload echo check.
2. `test_get_firmware_version.py` — firmware-version command, main + bootloader.
3. `test_get_comprehensive_position.py` — motor/hall/encoder position.
4. `test_get_temperature.py` — temperature command under load + thermal limit.
5. `test_go_to_position.py` — position moves in multiple units.
6. `test_move_with_velocity.py` — velocity moves in multiple units.
7. `test_move_with_acceleration.py` — acceleration moves in multiple units.
8. `test_homing.py` — homing in multiple units/directions.
9. `test_fast_short_move_with_velocity.py` — many short queued moves.
10. `test_gradual_speed_up.py` — ramp velocity to the speed limit.
11. `test_communication_while_high_speed.py` — ping stress during a fast profile.
12. `test_random_speed_stress.py` — multi-motor random-speed stress test.
13. `test_test_mode.py` — test-mode command, invalid/fatal-error scenarios.
14. `test_trigger_framing_error.py` — RS485 framing-error detect/recover.

NOTE: `test_get_product_info.py` exists in the folder but is **not catalogued in
`TEST_SUMMARY.md`**, so the runner does not pick it up. Add a row for it (and
audit for other uncatalogued tests) so coverage is not silently lost.

### Obsolete tests (use the old `communication` module — 9)
`test_all_leds_on`, `test_enable_disable`, `test_iterate_reset_and_enable`,
`test_go_to_closed_loop_mode` (+ 3 closed-loop variants),
`test_time_sync`, `test_time_sync_multiple_devices`,
`test_motor_position_vs_hall_sensor_position_vs_external_encoder_position`.
These still contain useful scenarios (LEDs, enable/disable, closed-loop entry,
time sync) but are not run and target the deprecated module.

### Non-hardware tests (all currently marked obsolete, none auto-run)
`test_servomotor_module_get_command_id.py` (unit test of `get_command_id`),
`test_terminal_formatting.py`, `test_getch.py`, `test_json_read.py`.

### KEY GAP — relevant to the MicroPython refactor
**There is no host-only test in the auto-run suite.** Every auto-run test needs
a physical motor on a serial port. Consequences:
- The `to_bytes` regression that broke the PC build would NOT be caught without
  hardware — there is no test that packs a command and checks the bytes.
- CI / quick pre-commit checks are impossible without a motor connected.

Recommended additions before refactoring (host-only, no motor needed):
- **Command-encoding tests**: for representative commands (and every parameter
  data type — u8/u16/u32/i32/u64, alias, unique-id, lists), build the packet and
  assert the exact bytes. Catches `to_bytes`/`from_bytes` and unit-conversion
  regressions directly.
- **Response-decoding tests**: feed known response byte streams, assert the
  parsed values (signed/unsigned across all widths).
- **CRC32 test**: assert `calculate_crc32` matches known vectors (also validates
  the pure-Python MicroPython implementation against `zlib`).
- **Import/smoke test**: `import servomotor; from servomotor import M3` plus
  building an `M3` instance — catches import-graph breakage.
These would run on both standard Python and MicroPython and form the safety net
the refactor verification plan depends on.

### Coverage assessment
Good hardware coverage of motion (position/velocity/acceleration/homing),
queuing, telemetry (position/temperature/firmware/product info), and error paths
(test mode, framing errors). Thin or missing: closed-loop mode (only in obsolete
tests), enable/disable and reset cycling (obsolete), time sync (obsolete),
device detection / alias assignment, and — critically — anything that runs
without hardware.

---

## B. Arduino library tests (`Arduino_library/`) — for awareness, not now

### How it works
- `build_tests.sh` compiles each `test_*.cpp` natively with `g++ -std=c++17`,
  linking `ArduinoEmulator.cpp` (emulates the Arduino API on the host) plus
  `Servomotor.cpp`, `Communication.cpp`, `DataTypes.cpp`,
  `AutoGeneratedUnitConversions.cpp`, `test_framework.cpp`.
- `run_all_tests.sh` builds, then runs each compiled `test_*` executable, and
  repeats the run in **two addressing modes** (alias and 16-hex-digit unique ID).
- Custom mini-framework in `test_framework.h/.cpp` (no external dependency).

### Test programs (8)
`test_emergency_stop`, `test_enable_disable_mosfets`,
`test_get_comprehensive_position`, `test_get_temperature`,
`test_move_with_acceleration`, `test_move_with_velocity`, `test_multi_move`,
`test_unit_conversions`.

Plus examples: `example_one_move`, `example_one_move_two_motors`,
`example_multi_move`, `example_trapezoid_move`.

### Notable
- `test_unit_conversions` builds **without** `-DREQUIRE_SERIAL_PORT` and runs
  with no hardware — this is exactly the kind of host-only test the Python suite
  lacks. Worth mirroring on the Python side.
- All other Arduino tests need a serial port + device ID.
- The directory is cluttered with many timestamped `.bak` files
  (`Servomotor.cpp.*.bak`, `Commands.h.*.bak`, etc.) and stray build artifacts
  (`*.o`, compiled `test_*` binaries) — a cleanup candidate, separate from
  testing work.

### Status
Per the project owner: the Arduino library is **not** being worked on soon. No
action proposed here — this section is informational only.

---

## Summary recommendation

Before implementing the MicroPython refactor:
1. Confirm the 14–15 hardware tests currently pass on standard Python against a
   real motor — this is the behavioural baseline.
2. Add a host-only test group (encoding / decoding / CRC32 / import smoke test)
   so regressions are caught without hardware and the same tests can later run
   under MicroPython.
3. Optionally modernise the still-useful obsolete tests (closed-loop,
   enable/disable, time sync) onto the `servomotor` module so they re-enter the
   auto-run suite.

Only once the suite is green should the four-module refactor in
`MICROPYTHON_COMPATIBILITY_DESIGN.md` proceed.

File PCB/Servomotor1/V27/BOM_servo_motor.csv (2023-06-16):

Source: | G:\OneDrive\Work\Upwork\TomRodinger\servo_motor_V27\servo_motor.kicad_sch
Date: | 6/16/2023 9:41
Tool: | Eeschema 7.0.1
Generator: | C:\Program Files\KiCad\7.0\bin\scripting\plugins/bom_csv_grouped_by_value.py
Component Count: | 108
Collated Components:
Item | Qty | Reference(s) | Value | LibPart | Footprint | Datasheet | DNP | Description | LCSC | MN | MPN
1 | 3 | C1, C5, C30 | 100pF | Device:C | Capacitor_SMD:C_0603_1608Metric | ~ |  | 50V 100pF C0G ±5% 0603 Multilayer Ceramic Capacitors MLCC - SMD/SMT ROHS | C14858 | Samsung Electro-Mechanics | CL10C101JB8NNNC
2 | 5 | C2, C22, C26, C32, C41 | 1uF | Device:C | Capacitor_SMD:C_0603_1608Metric | ~ |  | 50V 1uF X5R ±10% 0603 Multilayer Ceramic Capacitors MLCC - SMD/SMT ROHS | C15849 | Samsung Electro-Mechanics | CL10A105KB8NNNC
3 | 2 | C3, C11 | 4.7uF | Device:C | Capacitor_SMD:C_0603_1608Metric | ~ |  | 16V 4.7uF X5R ±10% 0603 Multilayer Ceramic Capacitors MLCC - SMD/SMT ROHS | C19666 | Samsung Electro-Mechanics | CL10A475KO8NNNC
4 | 1 | C4 | NC | Device:C | Capacitor_SMD:C_0603_1608Metric | ~ |  | NC
5 | 13 | C6, C7, C10, C12, C14, C15, C19, C21, C24, C27, C29, C31, C34 | 10uF | Device:C | Capacitor_SMD:C_0805_2012Metric | ~ |  | 50V 10uF X5R ±10% 0805 Multilayer Ceramic Capacitors MLCC - SMD/SMT ROHS | C440198 | Murata Electronics | GRM21BR61H106KE43L
6 | 9 | C8, C9, C13, C16, C18, C25, C28, C35, C36 | 100nF | Device:C | Capacitor_SMD:C_0603_1608Metric | ~ |  | 50V 100nF X7R ±10% 0603 Multilayer Ceramic Capacitors MLCC - SMD/SMT ROHS | C14663 | YAGEO | CC0603KRX7R9BB104
7 | 3 | C17, C20, C23 | 1nF | Device:C | Capacitor_SMD:C_0603_1608Metric | ~ |  | 50V 1nF X7R ±10% 0603 Multilayer Ceramic Capacitors MLCC - SMD/SMT ROHS | C1588 | Samsung Electro-Mechanics | CL10B102KB8NNNC
8 | 1 | C33 | 10uF | Device:C | Capacitor_SMD:C_0603_1608Metric | ~ |  | 10V 10uF X5R ±10% 0603 Multilayer Ceramic Capacitors MLCC - SMD/SMT ROHS | C19702 | Samsung Electro-Mechanics | CL10A106KP8NNNC
9 | 1 | D1 | 1N4148WS | :1N4148WS_1 | Diode_SMD:D_SOD-323 | https://www.vishay.com/docs/85751/1n4148ws.pdf |  | 100V 200mW Single 1.25V@150mA 4ns 150mA SOD-323 Switching Diode ROHS | C2128 | Jiangsu Changjing Electronics Technology Co., Ltd. | 1N4148WS
10 | 2 | D2, D5 | 1N4148WS | Diode:1N4148WS | Diode_SMD:D_SOD-323 | https://www.vishay.com/docs/85751/1n4148ws.pdf |  | 100V 200mW Single 1.25V@150mA 4ns 150mA SOD-323 Switching Diode ROHS | C2128 | Jiangsu Changjing Electronics Technology Co., Ltd. | 1N4148WS
11 | 1 | D3 | KT-0603R | Device:LED | LED_SMD:LED_0603_1608Metric | ~ |  | Red 0603 Light Emitting Diodes | C2286 | Jiangsu Changjing Electronics Technology Co., Ltd. | 1N4148WS
12 | 1 | D4 | 19-217/GHC-YR1S2/3T | Device:LED | LED_SMD:LED_0603_1608Metric | ~ |  | LED GREEN CLEAR SMD | C72043 | Hubei KENTO Elec | KT-0603R
13 | 8 | H1, H2, H3, H4, H5, H6, H7, H8 | MountingHole_Pad | Mechanical:MountingHole_Pad | servo_motor:Mounting Hole 3.5mm | ~ |  | MountingHole_Pad
14 | 1 | J1 | Serial Port | Connector:Conn_01x04_Male | Connector_PinHeader_2.54mm:PinHeader_1x04_P2.54mm_Vertical | ~ |  | 2.54mm Plugin Black 1x4P Plugin | C2691448 | XFCN | PZ254V-11-04P
15 | 1 | J2 | Programming | Connector:Conn_01x05_Male | Connector_PinHeader_2.54mm:PinHeader_1x05_P2.54mm_Vertical | ~ |  | 2.54mm Plugin Black Brass 1x5P Plugin | C492404 | XFCN | PZ254V-11-05P
16 | 1 | J3 | Screw_Terminal_01x03 | Connector:Screw_Terminal_01x03 | servo_motor:MOTOR | ~ |  | Screw_Terminal_01x03
17 | 1 | J4 | RS485 | Connector:Conn_01x04_Male | Connector_PinHeader_2.54mm:PinHeader_1x04_P2.54mm_Vertical | ~ |  | 2.54mm Plugin Black 1x4P Plugin | C2691448 | XFCN | PZ254V-11-04P
18 | 1 | J5 | Power IN | Connector:Conn_01x02_Male | TerminalBlock:TerminalBlock_bornier-2_P5.08mm | ~ |  | P=5.08mm Screw termina | C8465 | Ningbo Kangnex Elec | WJ500V-5.08-2P
19 | 1 | J6 | Encoder | Connector:Conn_01x05_Male | Connector_PinHeader_2.54mm:PinHeader_1x05_P2.54mm_Vertical | ~ |  | 2.54mm Plugin Black Brass 1x5P Plugin | C492404 | XFCN | PZ254V-11-05P
20 | 2 | P1, P3 | Board_to_Board_Connector | servo_motor:Board_to_Board_Connector | servo_motor:board_to_board_male |  |  | Board_to_Board_Connector
21 | 2 | P2, P4 | Board_to_Board_Connector | servo_motor:Board_to_Board_Connector | servo_motor:board_to_board_female |  |  | Board_to_Board_Connector
22 | 6 | Q1, Q2, Q3, Q4, Q5, Q6 | CRTM025N03L | servo_motor:CRTM025N03L | servo_motor:CRTM025N03L |  |  | 30V 98A 2.5mΩ@10V,50A 2.5W N Channel DFN-8-EP(6x5) | C467170 | CRMICRO | CRTM025N03L
23 | 1 | Q7 | MMBT3904 | Transistor_BJT:MMBT3904 | Package_TO_SOT_SMD:SOT-23 | https://www.onsemi.com/pub/Collateral/2N3903-D.PDF |  | 40V 200mW 100@10mA,1V 200mA NPN SOT-23 | C20526 | Jiangsu Changjing | MMBT3904
24 | 1 | Q8 | 2N3906 | Transistor_BJT:2N3906 | Package_TO_SOT_SMD:SOT-23 | https://www.onsemi.com/pub/Collateral/2N3906-D.PDF |  | 40V 350mW 100@10mA,1V 200mA PNP SOT-23 | C147294 | KEC Semicon | 2N3906S-RTK/P
25 | 1 | R1 | 1M | Device:R | Resistor_SMD:R_0603_1608Metric | ~ |  | 100mW Thick Film Resistors ±1% 1MΩ 0603 Chip Resistor - Surface Mount ROHS | C22935 | UNI-ROYAL(Uniroyal Elec) | 0603WAF1004T5E
26 | 2 | R2, R29 | 4.7K | Device:R | Resistor_SMD:R_0603_1608Metric | ~ |  | 100mW Thick Film Resistors ±1% 4.7kΩ 0603 Chip Resistor - Surface Mount ROHS | C23162 | UNI-ROYAL(Uniroyal Elec) | 0603WAF4701T5E
27 | 1 | R3 | 10M | Device:R | Resistor_SMD:R_0603_1608Metric | ~ |  | 100mW Thick Film Resistors ±1% 10MΩ 0603 Chip Resistor - Surface Mount ROHS | C7250 | UNI-ROYAL(Uniroyal Elec) | 0603WAF1005T5E
28 | 14 | R4, R5, R8, R10, R13, R15, R17, R20, R21, R22, R23, R24, R25, R27 | 10K | Device:R | Resistor_SMD:R_0603_1608Metric | ~ |  | 100mW Thick Film Resistors ±100ppm/℃ ±1% 10kΩ 0603 Chip Resistor - Surface Mount ROHS | C25804 | UNI-ROYAL(Uniroyal Elec) | 0603WAF1002T5E
29 | 1 | R6 | 33K | Device:R | Resistor_SMD:R_0603_1608Metric | ~ |  | 100mW Thick Film Resistors ±1% 33kΩ 0603 Chip Resistor - Surface Mount ROHS | C4216 | UNI-ROYAL(Uniroyal Elec) | 0603WAF3302T5E
30 | 1 | R7 | 680K | Device:R | Resistor_SMD:R_0603_1608Metric | ~ |  | 100mW Thick Film Resistors ±1% 680kΩ 0603 Chip Resistor - Surface Mount ROHS | C25822 | UNI-ROYAL(Uniroyal Elec) | 0603WAF6803T5E
31 | 1 | R9 | 300K | Device:R | Resistor_SMD:R_0603_1608Metric | ~ |  | 100mW Thick Film Resistors ±1% 300kΩ 0603 Chip Resistor - Surface Mount ROHS | C23024 | UNI-ROYAL(Uniroyal Elec) | 0603WAF3003T5E
32 | 1 | R11 | 470 | Device:R | Resistor_SMD:R_0603_1608Metric | ~ |  | 100mW Thick Film Resistors ±1% 470Ω 0603 Chip Resistor - Surface Mount ROHS | C23179 | UNI-ROYAL(Uniroyal Elec) | 0603WAF4700T5E
33 | 3 | R12, R18, R19 | 1.5K | Device:R | Resistor_SMD:R_0603_1608Metric | ~ |  | 100mW Thick Film Resistors ±1% 1.5kΩ 0603 Chip Resistor - Surface Mount ROHS | C22843 | UNI-ROYAL(Uniroyal Elec) | 0603WAF1501T5E
34 | 2 | R14, R16 | 25121WF100MT4E | Device:R | Resistor_SMD:R_2512_6332Metric | ~ |  | 1W 10mΩ ±800ppm/℃ ±1% 2512 Current Sense Resistors" | C127692 | UNI-ROYAL(Uniroyal Elec) | 25121WF100MT4E
35 | 1 | R26 | 1K | Device:R | Resistor_SMD:R_0603_1608Metric | ~ |  | 100mW Thick Film Resistors ±1% 1kΩ 0603 Chip Resistor - Surface Mount ROHS | C21190 | UNI-ROYAL(Uniroyal Elec) | 0603WAF1001T5E
36 | 2 | RST1, SW1 | TS-1187A-B-A-B | Switch:SW_Push | Button_Switch_SMD:SW_SPST_TL3342 | ~ |  | SPST SMD Tactile Switches | C318884 | XKB Connectivity | TS-1187A-B-A-B
37 | 1 | TH1 | 100k 1% NTC | Device:Thermistor_NTC | Resistor_SMD:R_0402_1005Metric | ~ |  | THERM NTC 100KOHM 4250K 0402 | C77130 | Murata Electronics | NCP15WF104F03RC
38 | 1 | TP1 | TestPoint | Connector:TestPoint | servo_motor:TestPoint 6mm | ~ |  | TestPoint
39 | 2 | U1, U9 | LM321 | Amplifier_Operational:LM321 | Package_TO_SOT_SMD:SOT-23-5 | http://www.ti.com/lit/ds/symlink/lm321.pdf |  | IC OPAMP GP 1 CIRCUIT SOT23-5 | C471859 | Texas Instruments | LM321LVIDBVR
40 | 1 | U2 | STM32G030C8T6 | dual_extruder:STM32G030C8T6 | servo_motor:STM32G030C8T6 |  |  | IC MCU 32BIT 64KB FLASH 48LQFP | C529329 | STMicroelectronics | STM32G030C8T6
41 | 1 | U3 | EG2133 | dual_extruder:EG2133 | Package_SO:TSSOP-20_4.4x6.5mm_P0.65mm |  |  | TSSOP-20 Gate Drive ICs | C190343 | EG Micro | EG2133
42 | 1 | U4 | Hall_Sensor*3 | servo_motor:Hall_Sensor*3 | servo_motor:hall_sensor_3 |  |  | Hall_Sensor*3
43 | 1 | U5 | SN75176BDR | Interface_UART:SN75176AD | Package_SO:SOIC-8_3.9x4.9mm_P1.27mm | http://www.ti.com/lit/ds/symlink/sn75176a.pdf |  | transceiver 1/1 SOIC-8 RS-485/RS-422 Ics | C7063 | Texas Instruments | SN75176BDR
44 | 1 | U11 | HT7533-1 | Regulator_Linear:HT75xx-1-SOT89 | Package_TO_SOT_SMD:SOT-89-3 | https://www.holtek.com/documents/10179/116711/HT75xx-1v250.pdf |  | 100mA Fixed 3.3V~3.3V Positive 30V | C14289 | Holtek Semicon | HT7533-1
45 | 1 | U12 | L78L10_SOT89 | :L78L10_SOT89_1 | Package_TO_SOT_SMD:SOT-89-3 | http://www.st.com/content/ccc/resource/technical/document/datasheet/15/55/e5/aa/23/5b/43/fd/CD00000446.pdf/files/CD00000446.pdf/jcr:content/translations/en.CD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 |  | Fixed 10V~10V Positive 35V | C122848 | Shikues | 78L10

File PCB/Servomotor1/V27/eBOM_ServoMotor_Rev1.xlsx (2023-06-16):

Item No. | Designator | Part Description | Manufacturer Part Number | Manufacturer Name | LCSC | Unit | Quantity Usage | Remark | Unit Price | Availability | Manufacturer Lead Time | Country of Origin
1 | C1, C5, C30 | 50V 100pF C0G ±5% 0603 Multilayer Ceramic Capacitors MLCC - SMD/SMT ROHS | CL10C101JB8NNNC | Samsung Electro-Mechanics | C14858 | PC | 3 |  | 0.0026 | 232823
2 | C2, C22, C26, C32, C41 | 50V 1uF X5R ±10% 0603 Multilayer Ceramic Capacitors MLCC - SMD/SMT ROHS | CL10A105KB8NNNC | Samsung Electro-Mechanics | C15849 | PC | 5 |  | 0.0184 | 423162
3 | C3, C11 | 16V 4.7uF X5R ±10% 0603 Multilayer Ceramic Capacitors MLCC - SMD/SMT ROHS | CL10A475KO8NNNC | Samsung Electro-Mechanics | C19666 | PC | 2 |  | 0.0152 | 54092
4 | C4 | NC
5 | C6, C7, C10, C12, C14, C15, C19, C21, C24, C27, C29, C31, C34 | 50V 10uF X5R ±10% 0805 Multilayer Ceramic Capacitors MLCC - SMD/SMT ROHS | GRM21BR61H106KE43L | Murata Electronics | C440198 | PC | 13 |  | 0.0798 | 257770
6 | C8, C9, C13, C16, C18, C25, C28, C35, C36 | 50V 100nF X7R ±10% 0603 Multilayer Ceramic Capacitors MLCC - SMD/SMT ROHS | CC0603KRX7R9BB104 | YAGEO | C14663 | PC | 9 |  | 0.0036 | 7187091
7 | C17, C20, C23 | 50V 1nF X7R ±10% 0603 Multilayer Ceramic Capacitors MLCC - SMD/SMT ROHS | CL10B102KB8NNNC | Samsung Electro-Mechanics | C1588 | PC | 3 |  | 0.0037 | 16034
8 | C33 | 10V 10uF X5R ±10% 0603 Multilayer Ceramic Capacitors MLCC - SMD/SMT ROHS | CL10A106KP8NNNC | Samsung Electro-Mechanics | C19702 | PC | 1 |  | 0.0122 | 1273676
9 | D1 | 100V 200mW Single 1.25V@150mA 4ns 150mA SOD-323 Switching Diode ROHS | 1N4148WS | Jiangsu Changjing Electronics Technology Co., Ltd. | C2128 | PC | 3 |  | 0.0113 | 48258
10 | D2, D5 | 100V 200mW Single 1.25V@150mA 4ns 150mA SOD-323 Switching Diode ROHS | 1N4148WS | Jiangsu Changjing Electronics Technology Co., Ltd. | C2128 | PC | 2 |  | 0.0113 | 48258
11 | D3 | Red 0603 Light Emitting Diodes | KT-0603R | Hubei KENTO Elec | C2286 | PC | 1 |  | 0.0055 | 763479
12 | D4 | LED GREEN CLEAR SMD | 19-217/GHC-YR1S2/3T | Everlight Elec | C72043 | PC | 1 |  | 0.0268 | 1107942
13 | H1, H2, H3, H4, H5, H6, H7, H8 | MountingHole_Pad
14 | J1 | 2.54mm Plugin Black 1x4P Plugin | PZ254V-11-04P | XFCN | C2691448 | PC | 1 |  | 0.0217 | 105286
15 | J2 | 2.54mm Plugin Black Brass 1x5P Plugin | PZ254V-11-05P | XFCN | C492404 | PC | 1 |  | 0.029 | 26280
16 | J3 | Screw_Terminal_01x03 |  |  |  | PC | 1
17 | J4 | 2.54mm Plugin Black 1x4P Plugin | PZ254V-11-04P | XFCN | C2691448 | PC | 1 |  | 0.0217 | 105286
18 | J5 | P=5.08mm Screw termina | WJ500V-5.08-2P | Ningbo Kangnex Elec | C8465 | PC | 1 |  | 0.1052 | 114884
19 | J6 | 2.54mm Plugin Black Brass 1x5P Plugin | PZ254V-11-05P | XFCN | C492404 | PC | 1 |  | 0.029 | 26280
20 | P1, P3 | Board_to_Board_Connector |  |  |  | PC | 2
21 | P2, P4 | Board_to_Board_Connector |  |  |  | PC | 2
22 | Q1, Q2, Q3, Q4, Q5, Q6 | 30V 98A 2.5mΩ@10V,50A 2.5W N Channel DFN-8-EP(6x5) | CRTM025N03L | CRMICRO | C467170 | PC | 6 | C2758433 propose |  | Non-stock
23 | Q7 | 40V 200mW 100@10mA,1V 200mA NPN SOT-23 | MMBT3904 | Jiangsu Changjing | C20526 | PC | 1 |  | 0.0102 | 5493451
24 | Q8 | 40V 350mW 100@10mA,1V 200mA PNP SOT-23 | 2N3906S-RTK/P | KEC Semicon | C147294 | PC | 1 |  | 0.0136 | 28964
25 | R1 | 100mW Thick Film Resistors ±1% 1MΩ 0603 Chip Resistor - Surface Mount ROHS | 0603WAF1004T5E | UNI-ROYAL(Uniroyal Elec) | C22935 | PC | 1 |  | 0.0013 | 1071788
26 | R2, R29 | 100mW Thick Film Resistors ±1% 4.7kΩ 0603 Chip Resistor - Surface Mount ROHS | 0603WAF4701T5E | UNI-ROYAL(Uniroyal Elec) | C23162 | PC | 2 |  | 0.0013 | 2762453
27 | R3 | 100mW Thick Film Resistors ±1% 10MΩ 0603 Chip Resistor - Surface Mount ROHS | 0603WAF1005T5E | UNI-ROYAL(Uniroyal Elec) | C7250 | PC | 1 |  | 0.0014 | 133253
28 | R4, R5, R8, R10, R13, R15, R17, R20, R21, R22, R23, R24, R25, R27 | 100mW Thick Film Resistors ±100ppm/℃ ±1% 10kΩ 0603 Chip Resistor - Surface Mount ROHS | 0603WAF1002T5E | UNI-ROYAL(Uniroyal Elec) | C25804 | PC | 14 |  | 0.001 | 13218517
29 | R6 | 100mW Thick Film Resistors ±1% 33kΩ 0603 Chip Resistor - Surface Mount ROHS | 0603WAF3302T5E | UNI-ROYAL(Uniroyal Elec) | C4216 | PC | 1 |  | 0.0012 | 512630
30 | R7 | 100mW Thick Film Resistors ±1% 680kΩ 0603 Chip Resistor - Surface Mount ROHS | 0603WAF6803T5E | UNI-ROYAL(Uniroyal Elec) | C25822 | PC | 1 |  | 0.0013 | 59144
31 | R9 | 100mW Thick Film Resistors ±1% 300kΩ 0603 Chip Resistor - Surface Mount ROHS | 0603WAF3003T5E | UNI-ROYAL(Uniroyal Elec) | C23024 | PC | 1 |  | 0.0012 | 151472
32 | R11 | 100mW Thick Film Resistors ±1% 470Ω 0603 Chip Resistor - Surface Mount ROHS | 0603WAF4700T5E | UNI-ROYAL(Uniroyal Elec) | C23179 | PC | 1 |  | 0.0013 | 1484564
33 | R12, R18, R19 | 100mW Thick Film Resistors ±1% 1.5kΩ 0603 Chip Resistor - Surface Mount ROHS | 0603WAF1501T5E | UNI-ROYAL(Uniroyal Elec) | C22843 | PC | 3 |  | 0.0012 | 431117
34 | R14, R16 | 1W 10mΩ ±800ppm/℃ ±1% 2512 Current Sense Resistors | 25121WF100MT4E | UNI-ROYAL(Uniroyal Elec) | C127692 | PC | 2 |  | 0.0521 | 22648
35 | R26 | 100mW Thick Film Resistors ±1% 1kΩ 0603 Chip Resistor - Surface Mount ROHS | 0603WAF1001T5E | UNI-ROYAL(Uniroyal Elec) | C21190 | PC | 1 |  | 0.001 | 8140972
36 | RST1, SW1 | SPST SMD Tactile Switches | TS-1187A-B-A-B | XKB Connectivity | C318884 | PC | 2 |  | 0.0155 | 338368
37 | TH1 | THERM NTC 100KOHM 4250K 0402 | NCP15WF104F03RC | Murata Electronics | C77130 | PC | 1 |  | 0.0136 | 42042
38 | TP1 | TestPoint
39 | U1, U9 | IC OPAMP GP 1 CIRCUIT SOT23-5 | LM321LVIDBVR | Texas Instruments | C471859 | PC | 2 |  | 0.2634 | 6669
40 | U2 | IC MCU 32BIT 64KB FLASH 48LQFP | STM32G030C8T6 | STMicroelectronics | C529329 | PC | 1 |  | 0.9148 | 64109
41 | U3 | TSSOP-20 Gate Drive ICs | EG2133 | EG Micro | C190343 | PC | 1 |  | 0.4503 | 2035
42 | U4 | Hall_Sensor*3 |  |  |  | PC | 1 | no information
43 | U5 | transceiver 1/1 SOIC-8 RS-485/RS-422 Ics | SN75176BDR | Texas Instruments | C7063 | PC | 1 |  | 0.276 | 28755
44 | U11 | 100mA Fixed 3.3V~3.3V Positive 30V | HT7533-1 | Holtek Semicon | C14289 | PC | 1 |  | 0.1297 | 247650
45 | U12 | 150mA 43dB@(120Hz) Fixed 10V~10V Positive 35V | 78L10 | Shikues | C122848 | PC | 1 |  | 0.0584 | 2950
 |  |  |  |  |  |  |  | DNP
 |  |  |  |  |  |  |  | Duplicate
 |  |  |  |  |  |  | A | LCSC basic part

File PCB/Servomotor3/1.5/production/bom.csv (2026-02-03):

Designator | Footprint | Quantity | Value | LCSC Part #
C1 | 0402 | 1 | 10nF | C15195
C10, C11, C12, C13, C14, C15, C16, C19, C7, C8 | 0603 | 10 | 10uF | C194427
C17, C20, C23 | 0402 | 3 | 1nF | C1523
C18, C2, C3, C36, C37, C41 | 0402 | 6 | 100nF | C307331
C21, C30 | 0402 | 2 | 100pF | C1546
C22, C35, C5, C9 | 0402 | 4 | 10uF | C15525
C24, C25, C26, C27, C29, C31, C32, C33, C34 | 0402 | 9 | 220pF | C1530
C28, C6 | 0402 | 2 | 1uF | C52923
C4 | 0402 | 1 | 4.7uF | C23733
D1 | 0603 | 1 | KT-0603R | C2286
D2 | 0603 | 1 | MHT192UGCT | C389519
J4 | PinSocket_1x06_P2.00mm_Vertical | 1 | Conn_01x06_Socket
R1, R3 | 2010 | 2 | 150m | C474275
R11, R12, R7, R9 | 0402 | 4 | 470R | C25117
R13, R15, R17, R2, R22, R23, R24, R25, R4, R5, R6 | 0402 | 11 | 10k | C25744
R26, R8 | 0402 | 2 | 1.5k | C25867
R27 | 0603 | 1 | 18k | C25810
R29 | 0402 | 1 | 4.7k | C25900
SW1, SW2 | TS3735PA-250gf | 2 | TS3735PA-250gf | C393946
TH1 | 0402 | 1 | 100k 1% NTC | C236279
U1 | QFN-28-1EP_5x5mm_P0.5mm_EP3.75x3.75mm_ThermalVias | 1 | ATD5833 | C5155089
U10 | DFN-8-1EP_3x3mm_P0.65mm_EP1.5x2.25mm | 1 | SIT3088E | C601076
U11 | SOT-23-5 | 1 | ME6211C33M5 | C82942
U2 | QFN-28_4x4mm_P0.5mm | 1 | STM32G031G8Ux | C432211
U3 | SOT-23-5 | 1 | LM321 | C19723728
U4, U6, U7 | DFN1616 | 3 | KTH3101 | C49258056

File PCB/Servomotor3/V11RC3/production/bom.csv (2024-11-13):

Designator | Footprint | Quantity | Value | LCSC Part #
C1 | 0402 | 1 | 10nF | C15195
C10, C11, C12, C13, C14, C15, C16, C19, C7, C8 | 0603 | 10 | 10uF | C194427
C17, C20, C23 | 0402 | 3 | 1nF | C1523
C18, C2, C21, C28, C3, C35, C36, C37, C41 | 0402 | 9 | 100nF | C307331
C22, C6, C9 | 0402 | 3 | 1uF | C52923
C30 | 0402 | 1 | 100pF | C1546
C4, C5 | 0402 | 2 | 4.7uF | C23733
D1 | 0603 | 1 | KT-0603R | C2286
D2 | 0603 | 1 | MHT192UGCT | C389519
J4 | PinSocket_1x06_P2.00mm_Vertical | 1 | Conn_01x06_Socket
R1, R3 | 2010 | 2 | 150m | C421741
R11 | 0402 | 1 | 470R | C25117
R12, R26, R8 | 0402 | 3 | 1.5k | C25867
R13, R15, R17, R2, R22, R23, R24, R25, R4, R5, R6 | 0402 | 11 | 10k | C25744
R27 | 0603 | 1 | 18k | C25810
R29 | 0402 | 1 | 4.7k | C25900
SW1, SW2 | TS3735PA-250gf | 2 | TS3735PA-250gf | C393946
TH1 | 0402 | 1 | 100k 1% NTC | C236279
U1 | QFN-28-1EP_5x5mm_P0.5mm_EP3.75x3.75mm_ThermalVias | 1 | ATD5833 | C5155089
U10 | DFN-8-1EP_3x3mm_P0.65mm_EP1.5x2.25mm | 1 | SIT3088E | C601076
U11 | SOT-23-3 | 1 | XC6206PxxxMR | C5446
U2 | QFN-28_4x4mm_P0.5mm | 1 | STM32G031G8Ux | C432211
U3 | SOT-23-5 | 1 | LM321 | C19723728
U4, U6, U7 | SOT-23 | 3 | AH49HSC | C510723

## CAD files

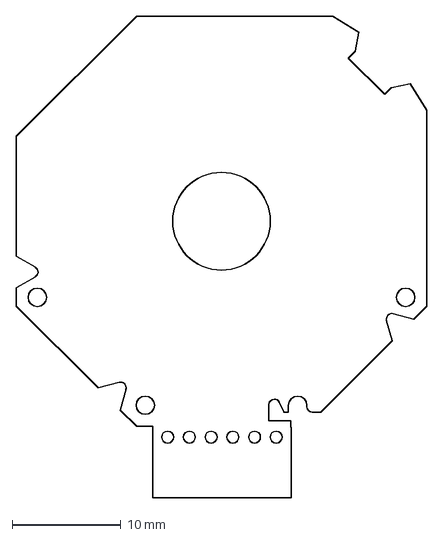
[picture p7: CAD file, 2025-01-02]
PCB/Servomotor3/1.0/PCB_outline_250101.DXF
37.8 x 44.4 mm

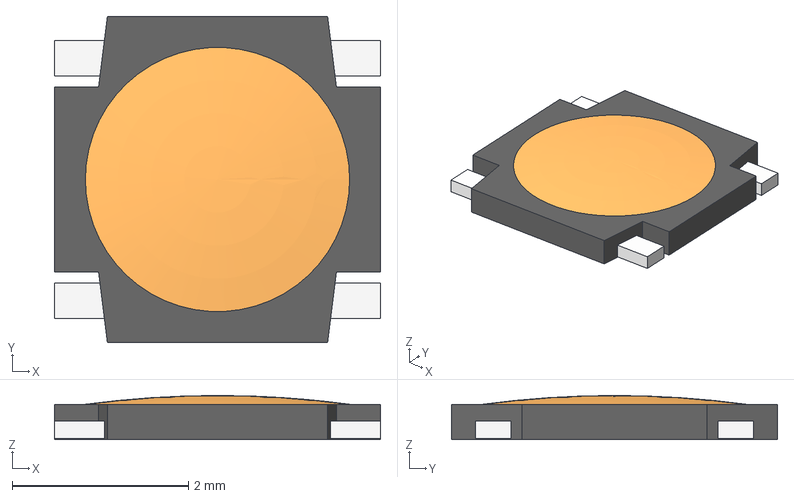
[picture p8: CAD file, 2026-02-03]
PCB/Servomotor3/1.5/3d_models/switch.step
3.70 x 3.70 x 0.5 mm

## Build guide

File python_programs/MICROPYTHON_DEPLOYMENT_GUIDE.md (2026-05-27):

# MicroPython Deployment Guide for ESP32-S3

This guide explains how to deploy and use the servomotor library on an ESP32-S3 running MicroPython.

## Prerequisites

1. **ESP32-S3 board** with MicroPython installed
2. **USB cable** to connect ESP32-S3 to your computer
3. **MicroPython firmware** (v1.19 or later recommended)
4. **Serial terminal** program (e.g., `screen`, `minicom`, or Thonny IDE)

## Hardware Setup

### Serial Connection to Servomotor
- **TX Pin**: GPIO 4 (ESP32-S3 to Servomotor RX)
- **RX Pin**: GPIO 5 (ESP32-S3 from Servomotor TX)
- **GND**: Common ground between ESP32-S3 and servomotor
- **Baud Rate**: 230400

```
ESP32-S3          Servomotor
  GPIO 4 (TX) --> RX
  GPIO 5 (RX) <-- TX
  GND         --- GND
```

## Installation Steps

### 1. Install MicroPython on ESP32-S3

If you haven't already installed MicroPython on your ESP32-S3:

```bash
# Download MicroPython firmware for ESP32-S3
# Visit: https://micropython.org/download/ESP32_GENERIC_S3/

# Erase flash
esptool.py --chip esp32s3 --port /dev/ttyUSB0 erase_flash

# Flash MicroPython firmware
esptool.py --chip esp32s3 --port /dev/ttyUSB0 write_flash -z 0x0 ESP32_GENERIC_S3-*.bin
```

### 2. Upload Servomotor Library to ESP32-S3

You need to copy the `servomotor` directory to your ESP32-S3. There are several methods:

#### Method A: Using ampy (Recommended)

```bash
# Install ampy
pip install adafruit-ampy

# Upload the entire servomotor directory
ampy --port /dev/ttyUSB0 put servomotor

# Upload JSON configuration files
ampy --port /dev/ttyUSB0 put servomotor/data_types.json servomotor/data_types.json
ampy --port /dev/ttyUSB0 put servomotor/motor_commands.json servomotor/motor_commands.json
ampy --port /dev/ttyUSB0 put servomotor/error_codes.json servomotor/error_codes.json
ampy --port /dev/ttyUSB0 put servomotor/unit_conversions_M3.json servomotor/unit_conversions_M3.json

# Upload your demo program
ampy --port /dev/ttyUSB0 put ball_juggling_demo.py
```

#### Method B: Using Thonny IDE

1. Open Thonny IDE
2. Select "MicroPython (ESP32)" from the interpreter dropdown
3. Select your ESP32-S3 port
4. Use File > Open to navigate to files
5. Right-click on `servomotor` folder and select "Upload to /"
6. Upload `ball_juggling_demo.py` to the root directory

#### Method C: Using WebREPL (if enabled)

1. Enable WebREPL on your ESP32-S3
2. Connect via web browser
3. Use the file upload feature to transfer files

### 3. Verify Installation

Connect to your ESP32-S3 via serial terminal:

```bash
# Using screen
screen /dev/ttyUSB0 115200

# Or using minicom
minicom -D /dev/ttyUSB0 -b 115200
```

In the MicroPython REPL:

```python
>>> import servomotor
>>> servomotor.get_platform()
'micropython'
>>> servomotor.is_micropython()
True
>>> servomotor.get_platform_info()
{'platform': 'micropython', 'is_micropython': True, 'is_esp32': True, ...}
```

## Running ball_juggling_demo.py

### Method 1: Direct Execution from REPL

```python
>>> import ball_juggling_demo
```

### Method 2: As main.py (Auto-run on boot)

```bash
# Rename and upload as main.py to auto-run on boot
ampy --port /dev/ttyUSB0 put ball_juggling_demo.py main.py
```

Then reset the board - the demo will run automatically.

### Method 3: Using exec()

```python
>>> with open('ball_juggling_demo.py') as f:
...     exec(f.read())
```

## Expected Output

When running successfully, you should see:

```
Running on MicroPython - file logging disabled
INFO: Opened UART on ESP32-S3 [TX=Pin(4), RX=Pin(5)]
INFO: Testing communication with device with alias X by pinging it 10 times
INFO: The device responded correctly to all the 10 pings
...
```

## Troubleshooting

### Problem: Import Error

**Error**: `ImportError: no module named 'servomotor'`

**Solution**: 
- Verify the servomotor directory was uploaded correctly
- Check that all required files are present using `import os; os.listdir('servomotor')`

### Problem: UART Not Working

**Error**: No response from servomotor

**Solution**:
- Check physical connections (TX, RX, GND)
- Verify baud rate (should be 230400)
- Test with a simple UART echo:
  ```python
  from machine import UART, Pin
  uart = UART(1, baudrate=230400, tx=Pin(4), rx=Pin(5))
  uart.write(b'test')
  ```

### Problem: Memory Error

**Error**: `MemoryError: memory allocation failed`

**Solution**:
- The ESP32-S3 has limited RAM. Try:
  - Reducing VERBOSE level
  - Importing only necessary modules
  - Running `import gc; gc.collect()` periodically
  - Consider using frozen modules (compile Python to bytecode)

### Problem: Platform Detection Issues

**Error**: Library tries to use standard Python features

**Solution**:
- Verify platform detection: `import sys; print(sys.implementation.name)`
- Should return `'micropython'`

## Memory Optimization Tips

1. **Use frozen modules**: Compile the servomotor library into the firmware
2. **Garbage collection**: Call `gc.collect()` periodically
3. **Reduce verbosity**: Set `VERBOSE = 0` in demos
4. **Selective imports**: Only import what you need

Example of memory-efficient usage:

```python
import gc
import servomotor

# Force garbage collection
gc.collect()

# Create motor instance with minimal verbosity
m = servomotor.M3(ord('X'), verbose=0)

# Your code here...

# Clean up when done
gc.collect()
```

## Performance Considerations

- **UART Speed**: 230400 baud is the standard speed
- **CPU Speed**: ESP32-S3 runs at 240MHz by default
- **Response Time**: Expect similar performance to standard Python for motor control
- **Memory**: ESP32-S3 has ~320KB RAM, sufficient for this library

## Updating the Library

To update the library on ESP32-S3:

```bash
# Remove old version
ampy --port /dev/ttyUSB0 rmdir servomotor

# Upload new version
ampy --port /dev/ttyUSB0 put servomotor
```

## Differences from Standard Python

The MicroPython version has these differences:

1. **No file logging**: Log files are not created
2. **No color terminal output**: Simple text messages only
3. **Simplified error messages**: Less verbose error reporting
4. **Fixed UART pins**: TX=Pin(4), RX=Pin(5) (cannot be changed without modifying code)
5. **No port selection menu**: UART is directly initialized

## Advanced: Creating Frozen Modules

For optimal memory usage, you can create frozen modules:

1. Clone MicroPython repository
2. Copy `servomotor` directory to `ports/esp32/modules/`
3. Rebuild firmware:
   ```bash
   cd micropython/ports/esp32
   make BOARD=ESP32_GENERIC_S3 clean
   make BOARD=ESP32_GENERIC_S3
   ```
4. Flash the new firmware

This embeds the servomotor library in ROM, freeing up RAM.

## Example: Minimal Motor Control

Here's a minimal example for testing:

```python
import servomotor
import time

# Open serial port (automatically uses correct pins)
servomotor.open_serial_port()

# Create motor instance
m = servomotor.M3(ord('X'), verbose=1)

# Reset and initialize
m.system_reset()
time.sleep(0.5)

# Test ping
test_data = b'\x01\x02\x03\x04\x05\x06\x07\x08\x09\x0A'
response = m.ping(test_data)
print("Ping response:", response)

# Enable motor
m.enable_mosfets()

# Get position
commanded, sensed, external = m.get_comprehensive_position()
print(f"Position - Commanded: {commanded}, Sensed: {sensed}")

# Close
servomotor.close_serial_port()
```

## Support

For issues specific to MicroPython deployment:
1. Check MicroPython documentation: https://docs.micropython.org/
2. Verify ESP32-S3 support: https://micropython.org/download/ESP32_GENERIC_S3/
3. Review this deployment guide for common solutions

For servomotor library issues:
1. Test on standard Python first to isolate platform-specific issues
2. Check that the library version supports cross-platform operation (v0.10.0+)
3. Verify all required JSON files are uploaded

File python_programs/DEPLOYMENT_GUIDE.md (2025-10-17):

# PyPI Deployment Guide

## Overview

The servomotor package deployment system has been enhanced to support both TestPyPI and production PyPI deployments with interactive selection and safety features.

## Key Features

### 1. Interactive Deployment Target Selection
The build script now prompts you to choose between:
- **TestPyPI** (test.pypi.org) - For testing packages before production
- **PyPI** (pypi.org) - Production deployment

### 2. Single Source of Truth Versioning
- Version is defined in `servomotor/__init__.py` as `__version__`
- `pyproject.toml` uses dynamic versioning to read from the source
- No need to update version in multiple places

### 3. Production Safety Features
- Confirmation dialog for production deployments
- Dynamic version display in warning messages
- Clear distinction between test and production environments

## Usage

### Basic Deployment

Run the deployment script:
```bash
./build_and_submit_to_PyPi.sh
```

The script will:
1. Build the package in an isolated virtual environment
2. Prompt you to select deployment target
3. Show appropriate warnings for production deployments
4. Upload to the selected repository

### Version Management

To increment the version:
1. Edit `servomotor/__init__.py`
2. Update the `__version__` variable (e.g., from "0.9.1" to "0.9.2")
3. Run the deployment script

Example:
```python
# In servomotor/__init__.py
__version__ = "0.9.2"
```

### TestPyPI Deployment
- Select option 1 when prompted
- Useful for testing package installation and functionality
- Available at: https://test.pypi.org/project/servomotor/

### Production PyPI Deployment
- Select option 2 when prompted
- Requires explicit confirmation with "yes"
- Shows current version in warning message
- Available at: https://pypi.org/project/servomotor/

## Installation Testing

### From TestPyPI
```bash
pip install --index-url https://test.pypi.org/simple/ servomotor==X.Y.Z
```

### From PyPI
```bash
pip install servomotor==X.Y.Z
```

### Verify Installation
```python
import servomotor
print(f"Version: {servomotor.__version__}")
from servomotor import M3
```

## Prerequisites

- PyPI credentials configured in `~/.pypirc`
- Valid API tokens for both TestPyPI and PyPI repositories
- Python 3.8+ environment

## Package Structure

The deployment includes:
- Core `servomotor` package with M3 motor control
- CLI tools: `servomotor_command`, `detect_and_set_alias_all_devices`, `show_device_information_for_all_devices`
- Terminal formatting utilities
- Vendored serial communication libraries

## Command Line Tools

After installation, the following commands are available:
- `servomotor_command` - Main command interface
- `detect_and_set_alias_all_devices` - Device detection and alias assignment
- `show_device_information_for_all_devices` - Display device information

## Troubleshooting

### Common Issues

1. **Version not found on TestPyPI**: Wait a few minutes for propagation
2. **Permission denied**: Check API token permissions
3. **Package already exists**: Increment version number

### Build Warnings

The build process may show setuptools deprecation warnings about license configuration. These are informational and don't affect functionality.

## Future Improvements

Consider updating `pyproject.toml` to use SPDX license expressions to resolve deprecation warnings:
```toml
license = "MIT"
```
Instead of:
```toml
license = { file = "LICENCE" }

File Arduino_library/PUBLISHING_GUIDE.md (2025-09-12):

# Guide to Publishing the Servomotor Library to Arduino Library Manager

This guide provides step-by-step instructions for publishing the Servomotor library to the Arduino Library Manager, making it available to anyone using the Arduino IDE.

## Prerequisites

- A GitHub account
- Git installed on your computer
- The Servomotor library files prepared with the correct structure

## Step 1: Prepare the Library Structure

The library has already been prepared with the correct structure using the `copy_stuff_to_Arduino.sh` script. This script creates the following structure:

```
Servomotor/
  ├── src/                 # Source files (.cpp)
  ├── examples/            # Example sketches
  │   ├── One_Move/
  │   │   └── One_Move.ino
  │   ├── One_Move_Two_Motors/
  │   │   └── One_Move_Two_Motors.ino
  │   └── Multi_Move/
  │       └── Multi_Move.ino
  ├── keywords.txt         # Keywords for syntax highlighting
  ├── library.properties   # Library metadata
  ├── LICENSE              # MIT License
  └── README.md            # Documentation
```

Run the script to create this structure:

```bash
./copy_stuff_to_Arduino.sh
```

## Step 2: Create a GitHub Repository

1. Go to [GitHub](https://github.com) and sign in to your account.
2. Click the "+" icon in the top-right corner and select "New repository".
3. Name the repository "Arduino-Servomotor" or similar.
4. Add a description: "Arduino library for controlling Gearotons servo motors".
5. Make the repository public.
6. Check "Add a README file" (this will be replaced later).
7. Choose "MIT License" from the "Add a license" dropdown.
8. Click "Create repository".

## Step 3: Clone the Repository

1. On your GitHub repository page, click the "Code" button and copy the repository URL.
2. Open a terminal and navigate to a directory where you want to clone the repository.
3. Run the following command:

```bash
git clone https://github.com/yourusername/Arduino-Servomotor.git
```

## Step 4: Copy the Library Files

1. Run the `copy_stuff_to_Arduino.sh` script to create the properly structured library in your Arduino libraries folder.
2. Copy all files from the Arduino library folder to your cloned repository:

```bash
cp -r /Users/tom/Documents/Arduino/libraries/Servomotor/* /path/to/cloned/Arduino-Servomotor/
```

## Step 5: Commit and Push the Library Files

1. Navigate to your cloned repository:

```bash
cd /path/to/cloned/Arduino-Servomotor
```

2. Add all files to the Git staging area:

```bash
git add .
```

3. Commit the changes:

```bash
git commit -m "Initial library release"
```

4. Push the changes to GitHub:

```bash
git push origin main
```

## Step 6: Create a Release

1. Go to your GitHub repository page.
2. Click on "Releases" in the right sidebar.
3. Click "Create a new release".
4. Enter a tag version (e.g., "v0.9.0") that matches the version in library.properties.
5. Enter a release title (e.g., "Servomotor Library v0.9.0").
6. Add release notes describing the library and its features.
7. Click "Publish release".

## Step 7: Submit to Arduino Library Manager

Arduino Library Manager reads your metadata directly from your repository's `library.properties` in tagged releases. Do not add custom JSON files.

1. Ensure your repository is public and the library is at the repository root with the standard structure (library.properties, src/, examples/, keywords.txt, LICENSE, README.md).
2. Create a Git tag that exactly matches the version in library.properties (e.g., `v0.9.0`) and publish a GitHub Release for that tag.
3. Go to the Arduino Library Registry and follow the "Submitting a library" instructions:
   - https://github.com/arduino/library-registry#submitting-a-library
4. Submit your library by opening the "Add your library" request as described there and provide your repository URL (e.g., `https://github.com/yourusername/Arduino-Servomotor`).

Once your submission is accepted, the indexer will process your latest release and your library will appear in the Arduino Library Manager.

## Step 8: Wait for Approval

The Arduino team will review your pull request. They may ask for changes or clarifications. Once approved, your library will be available in the Arduino Library Manager.

## Step 9: Update the Library

When you want to update the library:

1. Make your changes to the library files.
2. Update the version number in library.properties.
3. Commit and push the changes to GitHub.
4. Create a new release with a new tag version.

The Arduino Library Manager will automatically detect the new release and make it available to users.

## Additional Resources

- [Arduino Library Specification](https://arduino.github.io/arduino-cli/0.21/library-specification/)
- [Arduino Library Manager FAQ](https://github.com/arduino/Arduino/wiki/Library-Manager-FAQ)

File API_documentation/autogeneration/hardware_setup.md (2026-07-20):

# Hardware Setup

This section covers everything needed to physically connect and power the servomotor before any software is involved.

## What you need

- One or more Gearotons servomotors (M17 series: M17-34, M17-40, M17-48, or M17-60).
- A DC power supply providing 12 to 24 V. Budget at least 1.1 A per motor at your chosen voltage (maximum current draw is 1.1 A for the M17-60/48/40 and 1.0 A for the M17-34; rated power 26.4 W for the larger models, 24.0 W for the M17-34).
- A USB-to-RS485 adapter (sold separately; any generic USB-to-RS485 adapter works). The host can be a Mac, PC, Raspberry Pi, Arduino, or ESP32.
- The motor ships with its 6-wire pigtail.

## Wiring

Each motor has a 6-pin connector and ships with a matching pigtail wire that plugs into it. The pigtail's six wires, in connector order, are:

- BLACK = GND (power supply negative)
- RED = motor + (power supply positive, +12 to +24 V)
- GREEN = RS485 line A
- BLUE = RS485 line B
- GREEN = RS485 line A (second set)
- BLUE = RS485 line B (second set)

There are two sets of A/B wires so that motors can easily be daisy-chained: one A/B pair comes from the previous device (or the RS485 adapter) and the other A/B pair continues on to the next motor. Electrically the two pairs are the same bus lines.

Connect RED to the supply + terminal and BLACK to the supply - terminal. Connect one GREEN wire to the A terminal and one BLUE wire to the B terminal of the RS485 adapter. Keep each A/B pair twisted if possible.

Grounding: run a common ground between the RS485 adapter's GND terminal and the motors. Because the motors' BLACK power leads are the same ground, tying the adapter's GND to the power supply's negative rail achieves this. A shared ground reference is standard RS485 practice; without one, RS485 communication can be unreliable.

Multiple motors: any number of motors share one bus and one adapter. Either daisy-chain them (adapter A/B into the first motor's first A/B pair, its second A/B pair on to the next motor, and so on) or wire them in a star (all A wires to the adapter's A terminal, all B wires to B) — the daisy chain is what the second A/B pair is for. Power is wired in parallel: all RED leads to supply +, all BLACK leads to supply -. No termination resistors are specified for this product; short benchtop buses typically work without them.

Power supply sizing with many motors: motor inrush and acceleration peaks add up. If many motors may accelerate simultaneously, either size the supply for coincident peaks (about 1.1 A each) or stagger the starts in software (even a random 0-1 s offset per motor spreads the peaks effectively).

## Serial link parameters

- Baud rate: 230400 (fixed — there is no autobaud), 8 data bits, no parity, 1 stop bit.
- The bus is half-duplex: only one device transmits at a time. Motion commands execute asynchronously on each motor, so the host can command one motor and immediately talk to others while the first moves.
- Each motor has a factory-programmed 64-bit unique ID and can be assigned a one-byte alias (0-251) for short addressing. Alias 255 is broadcast to all devices.

## LED indicators

- GREEN flashing slowly (about once per second): heartbeat — the application firmware is running normally.
- GREEN flashing quickly: the bootloader is running instead of the application (the device is not ready for normal commands; send 'System reset' to relaunch the application).
- GREEN also lights briefly while a packet is being received, so you will see it flicker with communication traffic on the bus.
- RED flashing a repeating count of N blinks with a pause: fatal error number N. Count the blinks or read the code with 'Get status'. An error code of 0 (only possible via a deliberately triggered test) shows the red LED continuously on.

## Buttons

The motor has two small buttons:

- Reset: resets the microcontroller. All volatile state (queued moves, zeroed position, limits, enabled state) returns to power-on defaults.
- Test: brief press = spin one way; hold more than 0.3 s and release = spin the other way; hold at least 2 s and release = enter closed loop mode; hold more than 15 s and release = run self-calibration. During calibration the shaft spins and MUST be free to rotate — remove any load first.

## Mechanical and environmental

- Standard NEMA 17 mounting: 42.2 x 42.2 mm faceplate with no protrusions. Body heights: M17-60 = 59.7 mm, M17-48 = 48.7 mm, M17-40 = 40.1 mm, M17-34 = 33.5 mm; shaft length 20.6 mm on all models. Weights: 470 / 360 / 285 / 210 g respectively.
- Rated torque: M17-60 = 0.65 N.m, M17-48 = 0.55 N.m, M17-40 = 0.42 N.m, M17-34 = 0.28 N.m. Rated maximum speed 560 RPM for all models (datasheet rating; also the firmware's default max-velocity limit, 9.333 rot/s). Measured unloaded top speed is about 516 RPM (~8.6 rot/s), intrinsic to the drive and the same at 20 V and 24 V; no unit reaches 560 RPM even with a free shaft. In closed-loop operation, commanding a speed above the attainable ceiling grows the tracking error without bound and trips the position-deviation fatal error (45) rather than reaching the speed.
- Built-in magnetic encoder; closed-loop PID control runs on-board at 31.25 kHz.
- Operating temperature 0 to +80 C; storage -20 to +60 C; humidity 20-80% RH non-condensing; IP20 (indoor use).
- Integrated over-voltage and over-temperature protection. Protection trips are fatal errors: the motor disables itself and latches the error code until reset (over-temperature trips at roughly 80 C internal; over-voltage at a firmware-set threshold of 32 V on the M17). Motor current is limited continuously by the firmware-set current limit rather than by a fatal-error trip.
- Regeneration warning: a rapidly decelerating or externally driven motor pumps energy back into the supply and raises the bus voltage. If the supply cannot absorb it, the overvoltage protection (fatal error 14) trips. Decelerate large inertias gently, and avoid spinning the shaft forcefully by hand while powered.

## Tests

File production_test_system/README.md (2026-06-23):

# Servomotor Production Test System

A backend-driven system for production-testing servomotors over RS485, built to
the specification in [`../PRODUCTION_TEST_PROPOSAL.md`](../PRODUCTION_TEST_PROPOSAL.md)
(the authoritative spec).  It runs a 15-phase test sequence on up to 144 motors
across three independent RS485 buses, stores all raw data, and scores pass/fail
in a separate, re-runnable post-processing stage.

## Quick start

```bash
cd production_test_system
./run.sh --sim       # simulated rack — no hardware needed; try the whole UI
# or
./run.sh             # real hardware; assign the three serial ports in the UI
```

Then open <http://localhost:8000/>.

To run the tests:

```bash
. .venv/bin/activate
python -m pytest
```

## Troubleshooting

If the system **wedges** — UI/detection stuck, a bus stuck `running`, "1
detection queued" that never clears, or high CPU — see **[`DEBUGGING.md`](DEBUGGING.md)**.
Short version: hit **`GET /api/debug/stacks`** first (it shows exactly what each
bus worker is doing), and check the durable log at `data/diagnostics.log`. These
always-on diagnostics (`backend/diagnostics.py`) capture the evidence so the
cause can be pinned without a restart.

## Design (how it maps to the spec)

* **One async worker thread per RS485 bus** (`bus_worker.py`), coordinated by
  `runner.py`.  **All test execution runs in the backend** — closing or
  reloading the browser never stops a run.  A WebSocket streams live state.
* **Two strictly separate stages:**
  * **Stage A — collection** (`phases/`, one module per phase): runs on the
    hardware and stores *all raw data* to SQLite (large arrays as binary blobs).
    No metrics, no PNGs, no pass/fail during collection.  A `system_reset`
    (+1 s bootloader-exit delay) is issued between phases.
  * **Stage B — post-processing** (`evaluation.py`, `png_generation.py`):
    triggered from Tab 2.  *Run Evaluation* derives metrics and applies the
    current criteria → fresh `phase_eval` rows (re-runnable; tagged with a
    criteria version).  *Generate PNGs* renders disposable plots into
    `data/plots/`, named by unique ID + plot type.  *Run Evaluation* grades the
    motors picked by the **Tab-2 Scope selector** — only the test set, or every
    motor in the database (`Runner.evaluate`) — the same selector that filters
    the device table and plots.  Each motor is graded on every enabled phase
    **plus any phase that has collected data even if that phase is now disabled**
    (`_phases_to_evaluate`), so a disabled phase's leftover data still resolves
    to green/red instead of being stuck on blue; a disabled phase never affects
    the motor's overall pass/fail.
* **Database** (`database.py`): SQLite in WAL mode — `motors`, `phase_data`
  (raw, never overwritten), `phase_eval` (derived + pass/fail).  Keyed on the
  8-byte hardware unique ID; `first_detected` is written once.
* **Untested-vs-tested colouring** (`detection.py`): each detected motor in the
  test set is shown **green** when no test work has been recorded for it yet, and
  **orange** (`⚠ already tested`) once it has any `phase_data` or `phase_eval` row
  (`Database.has_any_test_data`).  Plain detection does *not* turn a motor orange —
  re-running detection any number of times leaves a fresh motor green, so the
  operator can spot which motors on a freshly loaded rack still need testing.  The
  colour is decided once per session and preserved across detection passes (run to
  beat RS485 collisions) so a re-detect never flips a colour mid-session.
* **Live collection-status grid** (`state.py`, `frontend/app.js`, `style.css`):
  the *Rack — live collection status* panel shows one tile per detected motor,
  and every tile is a **15-cell mini-grid** (P1…P15, laid out 3 rows × 5
  columns). Each cell is the live status of that one phase, in five colours:
  **grey** = no data collected, **yellow** = under test right now, **blue** =
  data collected and awaiting evaluation, **green** = evaluated and passed,
  **red** = evaluated and failed. The status is derived in `phase_grid_from_db`
  (per phase: no `phase_data` → grey; data with no up-to-date `phase_eval` →
  blue; an eval at/after the latest data → green when *pass or operator-cleared*,
  else red; re-collecting newer data reverts the cell to blue, i.e. "pending
  re-evaluation"). A freshly detected motor is seeded from the database, so prior
  results show immediately; during a run, each phase **auto-evaluates the instant
  a motor finishes it** — `CollectionContext.store` writes the `phase_data` row,
  immediately evaluates just that (motor, phase), and colours the cell green/red
  (the active phase shows yellow while collecting, and several motors tested in
  parallel show several yellow cells at once). The blue "pending evaluation"
  state therefore only appears transiently or as a fallback if auto-evaluation
  can't run. *Run Evaluation* (Tab 2) re-grades everything and refreshes the
  whole grid via `Runner.refresh_grid_from_db` (e.g. after a criteria change).
  The Phase 15 LED test holds its cell yellow while it awaits the human yes/no,
  then goes straight to green/red once the observation is graded
  (`Runner._grade_led`).
* **Phase enables card** (`frontend/app.js`, `index.html`, `style.css`): all
  enable/disable controls live in one **Phase enables** card on Tab 1 (between
  *Detection* and *Run*) rather than a checkbox inside each phase tab.  The card
  holds 15 two-state toggle buttons (P1…P15, same label as the tabs) that wrap
  across rows; **green = enabled**, **grey = disabled**.  Below them, **Select
  All** / **Select None** flip every phase at once.  Each toggle calls
  `setPhaseEnabled`, which persists via `POST /api/phases/N`, updates
  `settings.phases[N].enabled`, and recolours both the button and the phase tab.
* **Enabled-phase tab colouring** (`frontend/app.js`, `style.css`): each
  per-phase tab (P1…P15) is tinted **light green** when that phase is enabled,
  and left the default **grey** when it is disabled — so the operator can scan
  the tab strip and see which tests will run without opening each tab.  The
  colour is applied from `settings.phases[N].enabled` when the tabs are built and
  toggled live (`setTabEnabledColour`) the moment a phase is toggled in the Phase
  enables card; the green survives the active-tab highlight (the blue underline
  still marks the selected tab).
* **Device identification — Database tab** (`frontend/app.js`, `runner.py`):
  each device row has two *locate-it-in-the-rack* buttons.  **Flash Green**
  re-triggers the Identify command (cmd 41) so the green LED flashes continuously
  until cancelled (the button toggles to *Cancel Green Flashing*); a single
  per-bus coordinator loop (`Runner._identify_loop`) services every flashing
  device on that bus, so **any number flash at once** over the shared RS485 line
  (the bus's worker is busy while flashing — Detect/Run on it wait until the
  flashes are cancelled or the cap elapses).  **Red and Green Solid** sends test
  mode 13 (both LEDs solid) which is the most visible but **locks up the motor**
  (recover only by power-cycling), so it arms with a 3 s *Lockup Imminent! Undo*
  window before firing, then disables both buttons (*You must Power Cycle the
  Device*).  Solid works while other devices on the same bus keep flashing.  A
  5-minute safety cap and the global **Cancel** both stop flashing.
* **Settings** (`settings.py`): one JSON file, **atomic writes**
  (temp → fsync → `os.replace`), reloaded at startup.
* **Library reuse**: the existing `servomotor` control library
  (`../python_programs/servomotor`) is reused for the command tables, unit
  conversions, CRC and packet encoding/decoding.  Because that library keeps its
  serial port in a module global (single-bus), `transport.py` adds a per-bus
  transport that reuses the library's encoder/decoder while owning its own
  serial port — so three buses run truly in parallel.  `simulator.py` is a
  drop-in command-level simulator used for hardware-free development and tests.

## Layout

```
backend/
  bootstrap.py        put servomotor lib on sys.path (reuse, not duplicate)
  config.py           paths + rack constants
  units.py            unit conversions (loaded from the library's own factors)
  transport.py        per-bus RS485 transport (reuses library encode/decode)
  simulator.py        command-level virtual rack (no hardware)
  motor_client.py     high-level per-motor command helpers
  settings.py         atomic JSON settings
  database.py         SQLite WAL storage
  state.py            live, in-memory state for the WebSocket
  detection.py        detect passes + untested(green)/tested(orange) colour logic
  bus_worker.py       one worker thread per bus (jobs: detect / run / reset)
  runner.py           coordinator + LED-test reconciliation + identify (flash/solid)
  phase_defs.py       phase metadata, params, criteria, measured items
  phases/             phase01..phase15 — Stage A collectors
  analysis/           hall peak-finder + thermal best-fit (pure functions)
  evaluation.py       Stage B metric derivation + criteria
  png_generation.py   Stage B plot rendering
  blobs.py            binary (de)serialization for large arrays
  demo.py             optional simulated rack for --sim
  app.py              FastAPI app: REST + WebSocket + static frontend (no-cache)
frontend/             plain HTML/JS/CSS (no build step)
tests/                pytest suite + simulator harness
data/                 (gitignored) SQLite DB, plots, settings.json
```

## Hardware bring-up notes (verify against firmware)

* Motor driver is the **AT5833**; encoder disk has **50 magnets** (N_POLES=50).
* **Calibration auto-reboots** — never send `system_reset` after `start_calibration`;
  keep the bus quiet for the hold, then read status once (pass only if zero).
* **Setting the alias auto-reboots**; every `system_reset` is followed by a 1 s delay.
* **Phase 8** peak-finder mirrors firmware `handle_calibration_logic`; the
  raw `HALL_PEAK_FIND_THRESHOLD = 2000` becomes **8000** here (captured data is
  4× = 64/16).
* **Phase 10 (overvoltage)** uses firmware test modes 74 (22 V) / 75 (26 V),
  added in **fw 0.15.1.0**; a trip is reported as fatal `ERROR_OVERVOLTAGE` (14).
  Enabled by default.
* **Phase 11 (thermal)** runs to the overtemperature cutoff (`ERROR_OVERHEAT`,
  fatal 40) or a max time, and arms a tight deviation limit after spin-up to
  catch a driver cut-out. It first broadcasts firmware test mode **76**
  (added in **fw 0.15.2.0**), which raises the overtemperature cutoff from
  ~80 °C to **~90 °C** so the driver IC is confirmed to have thermal margin under
  load; the firmware restores the default cutoff at the next system reset. The
  pass check requires the last temperature to exceed `overtemp_threshold`
  (default **85 °C**) to corroborate the raised cutoff. **Phase 9** uses a
  low-current closed-loop move and a
  PID-deviation band (current is in internal units, 0–390). See the per-phase
  sections in `../PRODUCTION_TEST_PROPOSAL.md`.
* **Phase 15 (LED test)** uses cmd 36 mode **13** (both LEDs) and locks the motor
  until a power cycle, so it runs **last**.
* The default thresholds are placeholders to be tuned from real captures via the
  Tab 2 / per-phase histograms.
* **Bring-up lessons** (collision-tolerant detection, serialized firmware flash,
  staggered calibration, trapezoid spins, etc.) are documented in the
  "Implementation Notes & Hardware Gotchas" section of the proposal.

### Phase 1 firmware flashing
Phase 1 broadcast-flashes the target release (default **0.15.2.0**) then reads
the version back. Flashing is **serialized across buses** (`_FLASH_LOCK` in
`firmware_flash.py`) — flashing all three at once corrupted a bus on the bench.
Validated on the rack (buses flashed 48/48 cleanly). Toggle off via the Phase 1
`flash_enabled` param to verify versions only.

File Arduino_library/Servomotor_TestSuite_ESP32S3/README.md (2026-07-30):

# Servomotor Arduino-library ON-DEVICE test suite (ESP32-S3)

Tests the Servomotor Arduino library **natively on Arduino-class hardware**: all
test modules compile into one firmware that runs on the custom Gearotons
ESP32-S3 RS485 controller, driving a real motor over Serial1 (RX=GPIO5,
TX=GPIO4) at 230400 baud.

## Architecture

- **`tm_*.cpp`** — one test module per command group (15 modules, ~250
  assertions total, mirroring the Python per-command test suite). Entry point:
  `void tm_<name>(void)`. Modules only use the `tf_framework.h` API.
- **`tf_framework.h/.cpp`** — portable mini framework: `TEST_RESULT`,
  `tfGetMotor()` (unique-ID addressed motor), `checkMotorError` (records, never
  exits), `printf` redirected to USB CDC.
- **`test_registry.cpp`** — the ordered table of tests, each with a known-bug
  annotation (expected failures until fixed) and a hang timeout.
- **`Servomotor_TestSuite_ESP32S3.ino`** — the harness:
  - runs **one test per boot** and **resets the ESP32-S3 between tests**
  - run progress + per-test pass/fail stats persist in **NVS flash** (survive
    reset AND power cycle)
  - a per-test **esp_timer watchdog** force-reboots on a hang; the next boot
    records the test as CRASH and continues the sequence
  - a stale run from a different firmware build is refused (build-id check)
  - serial **CLI** to trigger tests over the debug link (`help`, `list`,
    `run`, `run <n>`, `results`, `detect`, `uid <hex>`, `stop`, `status`)
- **`truncated_frame_test.cpp`** + **`build_truncated_frame_test.sh`** +
  **`run_truncated_frame_test.py`** — a standalone transport-layer regression test for
  `Communication::getResponse()`, needing **no motor and no hardware**. It creates a
  pseudo-terminal and plays a scripted fake device on the far end, so a reply that starts
  and never finishes can be produced on demand (a real motor cannot be asked to truncate a
  reply on cue). Four cases: `silent`, `truncated`, `resync`, `partial`. It guards the
  0.10.1 fix for the receive hang — before that fix, `truncated` hung forever and `partial`
  left a stale byte that surfaced as a spurious `-7` on the next command. Suitable for CI.

- **`host_main.cpp`** + **`build_host_suite.sh`** — the SAME modules also build
  on the Mac against `../ArduinoEmulator.h` for quick iteration without
  flashing: `./host_suite <port> <16-hex-uid> [all|<index>|<name>]`.
- **`run_suite_mac.py`** — Mac-side orchestrator: resets the board, sends
  `run`, collects the streamed log across the between-test reboots, echoes the
  final summary, exit code 0 iff no *unexpected* failures.

## Usage

```bash
./flash_suite.sh                      # refresh installed lib + compile + flash
python3 run_suite_mac.py              # full run (all tests, reset between each)
python3 run_suite_mac.py --only 5     # single test by index
python3 run_suite_mac.py --attach     # just watch an already-active run
```

The suite streams `TEST_START` / `TEST_DONE` / `TEST_CRASH` markers plus every
assertion; the final table (`==== SUITE RESULTS ====` / `SUITE_SUMMARY ...
unexpected=K`) comes from NVS, so it is complete even if the Mac attached late.

## Known-bug annotations

Tests marked with registry bugs assert the CORRECT behavior on purpose and are
EXPECTED to fail until the bugs are fixed (then they should flip to PASS):

- `product_info` — BUG-25 (Get product description: fixed-size struct vs
  null-terminated string)
- `varlen_bugs` — BUG-26/27 (Capture hall sensor data / Read multipurpose
  buffer: fixed-size struct vs variable-length response)
- `time` — BUG-28 (Get current time / Time sync: 32× error, codegen not
  InternalUnit-aware)

`SUITE_SUMMARY unexpected=` counts only failures NOT covered by these
annotations (crashes always count as unexpected).

## Notes

- The device build uses the INSTALLED library (`~/Documents/Arduino/libraries/
  Servomotor`); `flash_suite.sh` refreshes it from the repo first so you never
  test stale code.
- Between-test state: `nvs` namespace `ardsuite`. A power cycle mid-run resumes
  where it left off.
- Do not use `Serial.printf` in modules (object-like `printf` macro).

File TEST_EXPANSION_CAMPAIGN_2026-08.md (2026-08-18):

# Test expansion campaign, August 2026

**Goal (Tom, 2026-08-04):** roughly DOUBLE the number of test cases. Think creatively about
what is NOT yet covered. Run everything on real hardware — the 35-motor rack AND the
ESP32-S3. When a firmware bug is found: investigate, establish the root cause, write it up
here, and **do NOT fix it**.

**This file is the durable record.** It survives context clears. Read it first to resume.

## HOW TO RESUME — current state and exact commands (2026-08-18)

**Hardware right now.** Always `ls /dev/cu.*` and probe first; the numbers move.

| what | port | state |
|---|---|---|
| 35-motor rack | `/dev/cu.usbserial-110` | all fw 0.15.12.0, all alias 88 → address by unique ID, left clean |
| bench M17 `99856389A2B46555` | `/dev/cu.usbmodem2101` | fw 0.15.12.0 (upgraded 2026-08-06), reached THROUGH the bridge |

**The ESP32-S3 currently holds the RS485 BRIDGE, not the on-device test suite.** That is why host
tools can reach the bench motor at all. To go back to on-device runs:
`Arduino_library/Servomotor_TestSuite_ESP32S3/flash_suite.sh`.

```bash
# build the host runner (needed after adding or editing any module)
cd Arduino_library/Servomotor_TestSuite_ESP32S3 && ./build_host_suite.sh

# run ONE module against the rack, or against the bench motor via the bridge
./host_suite /dev/cu.usbserial-110  5E2E8161CF1D2624 <module>
./host_suite /dev/cu.usbmodem2101   99856389A2B46555 <module>

# after writing a new tm_*.cpp — never hand-edit test_registry.{h,cpp}
./register_modules.py --apply

# which commands are thinly covered?
./coverage_report.py --gaps 8

# hardware-free suites (fast, run these before committing)
cd ../../python_programs && python3 run_host_tests.py          # 12 tests
python3 test_fleet_consistency.py -p /dev/cu.usbserial-110     # all 35 motors agree
```

**BEFORE trusting any hardware result:** `pgrep -f host_suite`. Two processes on one RS485 bus
corrupt each other silently and the failures look exactly like device faults.

**Upgrading the bench motor** (or any motor behind a microcontroller): flash the bridge, then use
`test_firmware_upgrade.py -p <port> -a X`, which is alias-addressed and ACKs every page.
`upgrade_firmware.py` in its default BROADCAST mode reports success for every page while verifying
nothing.

## Baseline at start (2026-08-04)

| | count |
|---|---|
| Arduino on-device modules (`tm_*.cpp`) | 63 |
| Arduino `TEST_RESULT` assertions (static) | 843 |
| Arduino assertions executed in a full run | 1042 |
| Python hardware tests (`test_*.py`) | 77 |
| Python host-only tests (`test_host_*.py`) | 9 |

**Target:** ~126 Arduino modules / ~1700 static assertions, and a meaningful increase on the
Python side. "Approximately double."

## Hardware

- **Rack:** `/dev/cu.usbserial-110`, 35 motors, ALL alias 88 → address by unique ID.
  Currently fw **0.15.12.0**. Shared resource: leave it reset, clean, alias 88, no fatal errors.
- **ESP32-S3:** `/dev/cu.usbmodem2101`, bench motor `99856389A2B46555` on its RS485 bus,
  currently fw **0.15.9.0**. Cannot be reflashed from the host (no serial path to that motor).
- **Host mode:** `Servomotor_TestSuite_ESP32S3/host_suite <port> <uid> <module>` runs the SAME
  Arduino modules from the Mac, so the rack can exercise the library against 0.15.12.0.

### Hard-won hardware lessons (do not relearn these)

- `run_all_tests.py` is a SINGLE-MOTOR suite. On the 35-motor rack it produces collision
  garbage, and `test_set_device_alias` **broadcasts**, which re-aliased all 35 motors from 88
  to 10. Individual tests mostly accept a 16-hex unique ID via `-a`; the runner does not.
- Arduino modules that broadcast or touch aliases are NOT rack-safe in host mode:
  `broadcast`, `multi_device`, `two_motors`, `addressing`, `wrong_addressing`, `alias_edges`,
  `uid_edges`. Also skip `calibration*` (needs a free shaft) and `bootloader_window`.
- Keep MOSFETs OFF where possible: the COMMANDED position advances regardless, so most
  planner/queue behaviour can be checked without anything turning. Rack-safe and load-safe.
- `cp` is aliased to `cp -i` here; a scripted restore can hang. Use python `shutil.copyfile`.
- Any new `.cpp` in the sketch folder is compiled into the DEVICE build — host-only files need
  `#if !defined(ARDUINO)`. And `Communication::openSerialPort()` is a no-op off-device, so host
  binaries must call `serialPort.begin(230400)` themselves or every test "passes" for the
  wrong reason.

## Cross-motor verification (2026-08-04)

The new modules were developed against one rack motor (`5E2E8161CF1D2624`). To rule out having
tuned them to that unit, five were re-run against a different one (`9474B90381CC1317`):

| module | motor 1 | motor 2 |
|---|---|---|
| `queue_accounting` | 20/20 | 20/20 |
| `determinism` | 21/21 | 21/21 |
| `error_taxonomy` | 29/29 | 29/29 |
| `stop_semantics` | 36/36 | 36/36 |
| `deviation_tracking` | 31/31 | 31/31 |

Identical throughout. Combined with `test_fleet_consistency.py` agreeing across all 35 motors,
the new tests are motor-independent.

## Command coverage: where the thin spots actually are

`Arduino_library/Servomotor_TestSuite_ESP32S3/coverage_report.py` maps every command in
`motor_commands.json` to its Arduino method and counts call sites across the `tm_*.cpp` modules.
Run `./coverage_report.py --gaps 8` for the thin tail.

Result as of 2026-08-04 (84 modules): **only ONE of 48 commands has zero uses** — `Firmware
upgrade` (cmd 23), which is destructive and slow and is owned by the Python suite instead. So
there is no blind spot at the command level.

The useful signal is the thin TAIL, which is where the remaining work should aim:

| uses | id | command |
|---|---|---|
| 2 | 7 | Capture hall sensor data — parameter-rich, has its own error codes 20/21/49 |
| 2 | 24 | Get product description |
| 3 | 9 | Get current time |
| 3 | 10 | Time sync |
| 3 | 37 | Get comprehensive position |
| 4 | 18 | Get product specs |
| 5 | 33 | Get hall sensor statistics |
| 5 | 35 | Read multipurpose buffer |
| 7 | 32 | Control hall sensor statistics |
| 7 | 39 | Get max PID error |

Caveat the script states itself: a HIGH count means "used often", not "well tested" —
`getPositionRaw` leads at 234 because it is how nearly every other assertion is measured. Only the
low end is meaningful, and counts understate commands that have both a converted and a `...Raw`
form.

## Ideas: areas believed UNCOVERED (working list)

1. Planner arithmetic: negative displacements, sign symmetry, values at int32/int64 edges
2. Composition: chained moves, superposition onto nonzero velocity, mixed move types
3. Unit-conversion boundaries: round-to-zero, float precision, extremes per unit
4. State-machine matrix: every command in every state (homing / calibrating / closed loop / fatal)
5. Limit interactions: changing limits mid-queue, safety fence vs planner, deviation limit
6. Queue arithmetic: exact 32-slot capacity, slot cost per move type, fill-to-exactly-full
7. Error recovery completeness: after EACH distinct fatal error, does reset fully restore?
8. Persistence: what survives reset vs power cycle
9. Timing: command floods during motion, back-to-back framing
10. Regression guards for the three 0.15.12.0 bugs (partly done in test_move_edge_cases.py)

## Findings

*(bugs found, with root cause; NOT fixed — see Tom's instruction)*

### F1 — Lowering `max_velocity` mid-move faults an already-validated move (behavioural, fw 0.15.12.0)

**Severity: not a crash; a usability/safety-design wart worth Tom's judgement. Not fixed.**

**What happens.** Queue a move that is legal under the current limits, then call
`set_maximum_velocity` with a value *below* the speed the move is already travelling at. The
motor immediately raises fatal **error 16, ERROR_VEL_TOO_HIGH**, aborts the move, and requires a
reset. Verified on rack motor `5E2E8161CF1D2624`, fw 0.15.12.0
(`tm_setting_timing` section 2b: ceiling 5 → 0.2 rot/s mid-move → `fatal=16`).

**Root cause.** Two independent velocity checks with different scopes:

1. *Queue time* — `add_to_queue()` checks the derived acceleration and the **predicted** velocity
   against the limits (`motor_control.c:1795`, `:1900`, `:1944`). This is what validates a move.
2. *Every control tick* — `motor_control.c:2187`:
   ```c
   if((current_velocity_i64 > max_velocity) || (current_velocity_i64 < -max_velocity)) {
       fatal_error(ERROR_VEL_TOO_HIGH);
   }
   ```
   This runs 31250 times a second against the **live** velocity and the **current** value of
   `max_velocity`.

`set_max_velocity()` (`motor_control.c:3341`) writes `max_velocity` immediately, with no reference
to what is in flight. So check 2 is evaluated against a limit the in-flight move was never
validated against, and the move that was legal one tick ago becomes a fatal error the next.

**Why it matters.** The obvious way to slow a machine down is to lower its speed limit. Doing that
while it is moving faults it instead — an abrupt uncommanded stop plus a latched fatal error, which
is the opposite of the intended effect. The safe orderings (stop first, or only ever *raise* the
limit mid-flight) are not stated anywhere in the API documentation.

**Options, if Tom wants it changed** (all deliberately NOT implemented):
- Leave as is and document the asymmetry in the API docs + `knowhow.md`. Cheapest, no firmware risk.
- Make `set_max_velocity` reject a value below the current in-flight speed with a *non-fatal*
  error, so the caller learns without the machine faulting.
- Have the new ceiling apply only from the next queue item, matching how the trapezoid shape is
  already latched at queue time.

**Regression guard in place:** `tm_setting_timing` asserts the current behaviour explicitly
(error 16), so whichever way this is resolved, the test will flag the change rather than silently
tracking it.

### F2 — A faulted motor can report only its error number: no telemetry survives a fault

**Severity: not a crash; a diagnostic limitation for Tom's judgement. Not fixed.**

**What happens.** Once a fatal error is latched, **`get_status` (cmd 16) is the only command that
returns a real reply.** Every other command — including `get position`, `get supply voltage`,
`get temperature`, `get current time`, `get firmware version`, `get product info`, `ping`,
`get hall sensor position` — answers with the latched error code instead of its data.
`system reset` still works and is the only way out.

Measured on rack motor `5E2E8161CF1D2624`, fw 0.15.12.0, probing twelve commands in two orders.
The rival explanation ("the first request after a fault is consumed") was ruled out deliberately:
`ping` is refused even when sent first, and `get_status` succeeds on the fourth consecutive call.
So it is a genuine per-command distinction.

**Root cause.** `fatal_error()` (`common_source_files/error_handling.c:169`) calls `__disable_irq()`
and never returns — it spins in a `while(1)` that flashes the red LED and hand-pumps the UART via
`systick_half_cycle_delay_plus_handle_commands()`. Inside that loop, `if_fatal_error_then_respond_flag`
causes an error packet to be transmitted for the pending command. `get_status` is the one handler
that completes and transmits its own reply first.

**Why it matters.** The behaviour is a sound fail-safe — a faulted machine SHOULD refuse to act, and
answering with the reason beats going silent. But it also means an operator whose motor just stopped
can retrieve exactly one number and nothing else. Temperature, supply voltage, position and the
clock are precisely the readings needed to work out *why* it faulted (overheat? brownout? mechanical
jam?), and all of them are unavailable at the only moment they matter.

**Options, if Tom wants it changed** (all deliberately NOT implemented):
- Leave as is, and document it in the API docs + `knowhow.md` — the cheapest option and no firmware
  risk. At minimum users should be told to poll telemetry *before* a fault, not after.
- Whitelist the read-only telemetry getters in the fatal-error loop alongside `get_status`. They
  touch no motor state and cannot restart motion, so the fail-safe property is preserved.
- Snapshot the key telemetry into the status reply at the moment `fatal_error()` fires, so the one
  answerable command carries the context with it.

**Regression guard in place:** `tm_fatal_state_commands` (25 assertions) asserts the current
contract in full — including that motion commands and `enableMosfets` stay refused, that the
original error code is not overwritten by later attempts, and that reset always recovers.

## Progress log

| when | what | result |
|---|---|---|
| 2026-08-04 | campaign started; baseline recorded | — |
| 2026-08-04 | `tm_planner_arithmetic` (38 assertions) | 38/38 on rack |
| 2026-08-04 | `tm_move_composition` (21 assertions) | 21/21 on rack |
| 2026-08-04 | `tm_unit_equivalence` (26 assertions) | 26/26 on rack |
| 2026-08-04 | `tm_queue_accounting` (20 assertions) | 20/20 on rack |
| 2026-08-04 | `tm_setting_timing` (19 assertions) | 19/19 on rack; surfaced finding **F1** |
| 2026-08-04 | `tm_determinism` (21 assertions) | 21/21 on rack |
| 2026-08-04 | `test_fleet_consistency.py` (15 checks) | 15/15 on 4 motors; 35-motor run in progress |
| 2026-08-04 | `tm_error_taxonomy` (29 assertions) | 29/29 on rack |
| 2026-08-04 | `tm_position_accumulator` (53 assertions) | 53/53 on rack |
| 2026-08-04 | `test_fleet_consistency.py` full run | **15/15 across all 35 motors**, 5m56s |

| 2026-08-04 | `tm_crc32_matrix` (25 assertions) | 25/25 on rack |
| 2026-08-04 | all 8 new modules on ESP32-S3 (fw **0.15.9.0**) | see "negative control" below |

| 2026-08-04 | `tm_multimove_bitmask` (14 assertions, 30 masks) | 14/14 on rack |
| 2026-08-04 | `tm_stop_semantics` (36 assertions) | 36/36 on rack |
| 2026-08-04 | `tm_time_domain` (32 assertions) | 32/32 on rack; surfaced finding **F2** |
| 2026-08-04 | `tm_fatal_state_commands` (25 assertions) | 25/25 on rack |
| 2026-08-04 | added `tf_motion_helpers.h` | shared setup so new modules avoid the known traps |

| 2026-08-04 | `tm_queue_underrun` (29 assertions) | 29/29 on rack, first try |
| 2026-08-04 | `tm_readonly_purity` (48 assertions) | 48/48 on rack, first try |
| 2026-08-04 | `tm_move_type_equivalence` (27 assertions) | 27/27 on rack, first try |
| 2026-08-04 | `test_host_data_file_integrity.py` (19 checks) | 19/19; host suite now 10/10 |

| 2026-08-04 | `tm_soak` (17 assertions, ~5 min) | 17/17 on rack |
| 2026-08-04 | `tm_command_state_matrix` (13 assertions, 36 cells) | 13/13 on rack |
| 2026-08-04 | `test_host_unit_parity.py` (45 checks) | 45/45 |

| 2026-08-04 | `tm_duration_extremes` (34 assertions) | 34/34 on rack |

| 2026-08-04 | `tm_reset_completeness` (19 assertions) | 19/19 on rack |
| 2026-08-04 | `tm_deviation_tracking` (31 assertions) | 31/31 on rack |

| 2026-08-04 | **11-module batch** (8 agent-authored + 3 hand-written) | **471/471 on a clean bus** |
| 2026-08-04 | `test_host_test_suite_hygiene.py` (10 checks) | 10/10; caught 2 wrong cmd numbers |

| 2026-08-04 | **batch 2** (8 agent-authored) | **323/323 on a clean bus** |

| 2026-08-05 | **batch 3** (8 agent-authored) | **312/312 on rack** (after 2 fixes) |
| 2026-08-05 | **batch 4** (8 agent-authored) | **307/307 on rack, all clean first try** |

**FINAL TOTALS (2026-08-05)**

| | baseline | final | change |
|---|---|---|---|
| Arduino on-device modules | 63 | **119** | +56 (1.89x) |
| Arduino static assertions | 843 | **2348** | +1505 (**2.79x**) |
| Python host-only tests | 9 | **12** | +3 |
| Python hardware tests | 77 | **78** | +1 |

The brief was to approximately DOUBLE the test cases. On assertions — the closest thing to a count
of test cases — the suite is at **2.79x** the baseline. On module count it is at 1.89x.
All 32 new modules pass on the rack; the host suite is 12/12.

### Batch 3 (312 assertions) and batch 4 (307 assertions)

| module | assertions | | module | assertions |
|---|---|---|---|---|
| `tm_repeated_command_idempotence` | 44 | | `tm_position_far_field` | 40 |
| `tm_power_on_defaults` | 40 | | `tm_unit_extreme_values` | 40 |
| `tm_homing_arithmetic` | 40 | | `tm_recovery_sequences` | 39 |
| `tm_concurrent_command_pressure` | 40 | | `tm_realistic_motion_patterns` | 39 |
| `tm_settings_interaction_matrix` | 39 | | `tm_streaming_motion` | 38 |
| `tm_response_field_integrity` | 39 | | `tm_firmware_compat_gating` | 38 |
| `tm_boundary_value_sweep` | 38 | | `tm_motion_timing_precision` | 37 |
| `tm_error_code_reachability` | 34 | | `tm_command_latency_profile` | 36 |

Batch 4 needed no fixes at all. Batch 3 needed two, and both turned into documented behaviour
rather than weakened tests: the `goToPosition` convergence property (observation O2) and the
safety-fence reply race (finding F3).

Notable results established by these two batches:
- **The 3-slot/2-slot planner frontier is exactly `max_acceleration_raw == 8 * max_velocity_raw`**
  (`delta_t1 = 16v/a`). One raw count either side flips the plan. The float setters cannot reach
  the boundary — `109951162.7776f` rounds to the wrong side — so the module uses the raw setters.
- **Homing has no arithmetic of its own**: its closed-loop precondition is evaluated first and
  unconditionally, so no parameter value (zero, negative, INT32_MIN, UINT32_MAX) changes the answer
  from error 13 — not even a zero duration, which would otherwise be 34.
- **The position accumulator is genuinely 96-bit**: identical behaviour 34 billion counts from the
  origin as at zero, across the 2^31 and 2^32 carry boundaries in both signs. The 32-bit absolute
  go-to layered on top fails loudly with `ERROR_MOVE_TOO_FAR` when its reach runs out, rather than
  wrapping.
- **Motion timing is deterministic**, not merely correct on average: a move runs for exactly the
  commanded number of 32 us ticks and stops on an exact tick, with bounded jitter.
- **300 moves streamed** through the 32-slot ring, topped up as it drains, never stall and land
  exactly on the origin.

### Batch 2, measured on a clean bus

| module | assertions |
|---|---|
| `tm_communication_statistics` | 45 |
| `tm_position_source_consistency` | 41 |
| `tm_time_sync_protocol` | 41 |
| `tm_status_flag_semantics` | 40 |
| `tm_multipurpose_buffer` | 40 |
| `tm_queue_ordering` | 39 |
| `tm_packet_size_encoding` | 39 |
| `tm_indicator_commands` | 38 |
| **total** | **323, zero failures** |

Two things the authoring agents got right that are worth keeping:
- One rejected a WRONG PREMISE in my brief. I asked it to prove the communication counters
  increment by sending pings; it read `common_source_files/RS485.c` and found there is no packet
  counter at all — all six are ERROR counters, so pings leave them at zero. It asserted the
  opposite (30 clean commands leave every counter at zero) and drove increments with malformed
  frames instead.
- The same module's rack safety rests on filter ORDERING: its injected frame is extended-addressed
  and too short to hold a command plus CRC32, so it dies at `RS485.c:255-259` on the target while
  every other motor discards it at the unique-ID comparison (`RS485.c:236-243`) *before* any
  counter is touched. The module asserts that ordering explicitly, which is what makes injecting
  malformed frames safe on a 35-motor bus.

### Batch 2 on the ESP32-S3 (fw 0.15.9.0) — 7 of 8 identical

Run against the pre-fix bench motor: `communication_statistics` 45/45, `indicator_commands` 38/38,
`packet_size_encoding` 39/39, `position_source_consistency` 41/41, `queue_ordering` 39/39,
`status_flag_semantics` 40/40, `time_sync_protocol` 41/41 — all matching the rack exactly.

`multipurpose_buffer` was 38/2. Both failures are the SAME pre-fix divide-by-zero already
documented: the module induces a fault with an over-speed move, and on 0.15.9.0 that move is
silently ACCEPTED (delta_t1 = 0 -> acceleration 0), so no fault latches and the "faulted motor
refuses the read" check has nothing to test. Not a new finding, and not a difference in the
multipurpose buffer itself.

### A pre-existing mislabel the hygiene guard was blind to

A batch-3 agent noticed that `tm_homing_edges.cpp:6` had called Homing "cmd 30" since it was
written. Homing is **cmd 14**; 30 is `Set safety limits`. Fixed.

`test_host_test_suite_hygiene.py` should have caught this and did not. Its regex captured the
literal text before the parenthesis — "HOMING command" — which is not a command name, so the check
found nothing to compare and silently passed. It now strips a leading "the " and a trailing
" command" before matching. **A guard that fails open is worse than no guard**, because it is
credited with coverage it does not have; this one was, for two days.
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

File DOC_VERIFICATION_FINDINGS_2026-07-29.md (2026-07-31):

# Source-verification findings, 2026-07-29

**Origin:** a real customer support case (Gearotons M17-40 + ESP32-S3, July 2026). The AI that
handled the case wrote `DOCUMENTATION_IMPROVEMENT_REPORT.md` (lives outside this repo, at
`/Users/tom/Projects/protein_purification_machine_Jeffs_lab/`). Acting on it, every technical
claim in that report — and a good deal of surrounding code — was re-verified against firmware,
Arduino library and Python package source by a 32-agent verification sweep.

**What was already done** (committed and pushed, `1b56b63`, `1d159c3`, `36c387b`):
the documentation work itself. See those commit messages for the full list.

**What this file is for:** everything the sweep found that was *not* acted on, because it is a
code change rather than a documentation change, or because it is outside the scope of that task.
All of it is source-verified with file:line unless explicitly marked otherwise. None of it was
bench-verified at the time of writing — see the status update immediately below for what has
since been fixed and tested.

---

## STATUS UPDATE 2026-07-30 — two items FIXED

Both of the items called out as highest-value have been fixed, tested on the bench
(ESP32-S3 + M17 motor) and SHIPPED as Arduino library v0.10.1 — verified live in the Arduino
Library Manager index on 2026-07-31, with the served ZIP confirmed to contain the fix.
The rest of this document is unchanged and still open; the top remaining item is the firmware
compute_trapezoid_move divide-by-zero in section 2.1, which needs a bench probe.

- **3.1 Arduino receive hang — FIXED.** Reproduced deterministically first, then fixed.
  `Communication.cpp` now computes the remaining receive budget through
  `remainingReceiveBudgetMs()`, which saturates at zero instead of wrapping, and
  `receiveBytes()` clamps a negative budget and compares unsigned-against-unsigned so the
  wait loop is provably terminating. Fixing only that turned out to trade the freeze for a
  poisoned NEXT command (the leftovers of the abandoned frame were parsed as the following
  reply's size byte, surfacing as a spurious `-7`), which was then also fixed: the error
  path calls the new `discardPartialFrame()`, which takes what is actually buffered instead
  of waiting for bytes that will never arrive. Arduino library version bumped to 0.10.1.
  Regression test: `Servomotor_TestSuite_ESP32S3/truncated_frame_test.cpp` +
  `run_truncated_frame_test.py` — four cases (silent / truncated / resync / partial), no
  hardware required, each verified to FAIL before the fix and PASS after.
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

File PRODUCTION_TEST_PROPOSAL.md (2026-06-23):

# Production Test System — Proposal

## Hardware Inside M17 (hw 1.5, scc3)

| Component | Part | Role |
|---|---|---|
| MCU | STM32G031G8 (Cortex-M0+, 64 MHz) | Main controller |
| Motor driver | AT5833 | Stepper driver, STEP/DIR interface from MCU; nFault fault line to MCU |
| Position sensors | 3× analog Hall sensors | ADC inputs; read by firmware for closed-loop position feedback |
| RS485 transceiver | SN65HVD3082 | 230,400 baud differential bus |
| Supply sense | Resistor divider → ADC | Measures input voltage |
| Temperature | ADC (thermistor) | Board temperature monitoring |
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

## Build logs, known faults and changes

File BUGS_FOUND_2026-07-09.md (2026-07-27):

# Bugs found during documentation ground-truth verification (2026-07-09)

## STATUS UPDATE 2026-07-14 — fix session results

Fixed in **firmware 0.15.4.0** (built, flashed to the bench motor, each fix
hardware-verified; full 47-example suite passed afterwards):

| Bug | Fix | Hardware verification |
| :-- | :-- | :-- |
| BUG-1 stale velocity planner | `clear_the_queue_and_stop_no_disable_interrupt()` now zeroes `velocity_after_last_queue_item` | Reproduced both symptoms on 0.15.3.3 (spurious error 28 on a legal move; accepted overspeed + runtime error 16 on an illegal one); same script shows correct behavior on 0.15.4.0 |
| BUG-2 Multimove stack overflow | count validated BEFORE the copy | 33-move packet → clean fatal error 24, device alive |
| BUG-3 Test mode 0 lockup | value 0 clears motor/overtemperature test modes + restores the overvoltage threshold; never enters the LED-test path | test_mode(0) returns success, device responsive, no error |
| BUG-4 ADD_TO_QUEUE_TEST desync | dry-run no longer commits planner state | code-reviewed (no host tooling drives cmd 120) |
| BUG-5 int64 overflow hole | overflow guard before the velocity prediction (both copies) | pathological accel×duration → clean fatal error 28 |
| BUG-6 zero-parameter family | duration 0 on all four move commands and max-acceleration 0 now raise fatal error 34 | all five cases verified |
| BUG-7 frozen status flags | `fatal_error()` refreshes flags to 0 | flags read 0x00 with error code intact in fatal state |
| BUG-11 silent empty buffer | empty-buffer read replies with data_type byte 0 | returns b'\x00' instead of timing out |
| BUG-16 LED comment | RS485.c comment now says green | n/a (comment) |

Fixed in the **Python library / codegen** (host tests + hardware-verified):

| Bug | Fix |
| :-- | :-- |
| BUG-8 counts_per_timestep factor | generator emits 2^20; unit_conversions_M3.json + Arduino files regenerated; 1 rot/s commanded in counts_per_timestep lands at exactly 2.000 rotations in 2 s |
| BUG-9 (TODO #8) time conversion | time tables are rescaled per the parameter's InternalUnit (microsecond-wire commands now convert correctly in every unit; velocity/acceleration tables deliberately untouched) |
| BUG-10 default time unit | units list reordered in the generator — 'seconds' is first, so it is the data-driven default (per Tom: defaults stay first-item-of-list) |
| BUG-12 hex unique-ID strings | M3 constructor parses 4+-char strings as hex unique IDs |
| BUG-13 M3 CRC control | `motor.set_crc32_enabled(False/True)` threads through to execute_command |
| BUG-14 auto-flush | detect_devices_iteratively() flushes the receive buffer before returning |

Consequential updates: tests test_time_sync / test_reset_time / test_get_current_time /
test_read_multipurpose_buffer updated to the corrected specifications; examples and
generated documentation updated with version-scoped notes.

Still open: **BUG-15** (stress-read reliability investigation), the datasheet
`indicators.py` red-LED-traffic staleness (datasheet regen pending), and the
temperature/broadcast-consistency review items.

## Post-fix code review round (2026-07-14/15, 8-angle review of the full diff)

Additional defects found and FIXED (firmware rebuilt as 0.15.4.0, re-flashed,
full battery + 47-example suite re-passed):

- fatal_error()'s new flags refresh would have erased the in-bootloader status
  bit on bootloader fatal errors (error_handling.c is linked into the
  bootloaders) — now preserves bit 0.
- The int64 overflow guard covered the velocity prediction but not the
  quadratic position term (accel × n(n+1)/2) — now one shared helper bounds
  both terms (velocity overflow → error 28, position overflow → error 27).
- The `ran_the_add_to_queue_test` flag permanently suppressed the
  ERROR_POSITION_DISCREPANCY safety check after any cmd-120 use; with the
  dry-run no longer corrupting the planner, the suppression was removed and
  the check runs unconditionally.
- add_to_queue_test read a stale queue slot for its position prediction
  (wrong-variable copy-paste, pre-existing) and silently accepted zero-duration
  moves — both fixed (parity with the real commands). NOTE: the dry-run no
  longer chains multi-segment predictions (its only consumer was the obsolete
  test_safety_limit.py).
- M3 constructor string parsing tightened: exactly 16 hex digits = unique ID
  (rejects IDs that collapse into the one-byte alias range, e.g. "00FF" would
  have become broadcast 255); other strings parse as decimal (restores the old
  behavior for "0100" etc.); reserved aliases 252/253/254 rejected everywhere.
- MicroPython _SimpleEnum now iterates in insertion order, so the
  first-item-is-default rule holds on the ESP32 too.
- New public servomotor.set_serial_port(port) API; all 47 examples use it
  instead of poking the communication.serial_port module global.
- The doc generator's unit-reference sections are now DERIVED from
  unit_conversions_M3.json (they had already drifted: claimed timesteps was the
  default and counts_per_timestep was broken — both stale after this session's
  fixes). The Arduino command methods were regenerated per the documented
  pipeline (their embedded comments carried pre-rewrite descriptions).
- motor_commands.json: the empty-buffer reply is a normal short-format packet
  (the extended-size format applies only to non-empty replies) — description
  corrected. test_time_sync.py verbose-mode NameError fixed.

Compatibility notes for the next library release (intentional breaking changes,
confirmed by Tom's rulings): the default time unit changed from 'timesteps' to
'seconds', and time_unit='timesteps' now converts truly (µs/32) for the clock
commands instead of passing raw microseconds through — scripts using the old
identity-passthrough workaround must switch to 'seconds' or 'microseconds'.

---

While verifying `error_codes.json` and `motor_commands.json` against the firmware
source (every claim traced to code), a number of real bugs surfaced. This file
documents them for fixing; **nothing here has been fixed yet** except where noted.

> **Line-number caveat:** `firmware/Src/main.c` and `firmware/Src/motor_control.c`
> references are against the working tree of 2026-07-09, which carries uncommitted
> PID/anti-windup edits. Line numbers in those two files may shift; function names
> and code excerpts are the stable reference.

---

## Firmware — high priority

### BUG-1: Stale `velocity_after_last_queue_item` after a mid-motion queue clear

**Component:** `firmware/Src/motor_control.c`
**Symptom:** after an 'Emergency stop' or 'Reset time' issued while the planned
end-of-queue velocity was nonzero (e.g. during a `Move with velocity`, or a
multimove whose last segment ends at nonzero velocity), every subsequently queued
acceleration-type move (trapezoid move, go-to-position, move-with-acceleration,
homing's internal trapezoid) is validated from a wrong velocity baseline. The
runtime then executes a *different* profile than was validated: the motor can
physically overspeed by the stale amount and trip fatal error 16
(`ERROR_VEL_TOO_HIGH`) mid-move, or raise spurious errors 26/27/28 at queue time,
and go-to-position moves land at offset positions.

**Root cause:** `clear_the_queue_and_stop_no_disable_interrupt()`
(motor_control.c:421-429) zeroes `current_velocity_i64` and re-syncs
`position_after_last_queue_item`, but never resets `velocity_after_last_queue_item`
(declared at :211). That variable is written only in `add_to_queue` (:1794) and
`add_to_queue_test` (:1889); the reset at :3584 exists only inside
`#ifdef MOTOR_SIMULATION`.

**Reachable via:** `EMERGENCY_STOP_COMMAND` → `emergency_stop()` (:3264-3270),
`RESET_TIME_COMMAND` → `reset_time()` (:3255-3262), homing-collision path (:1415).

**Fix candidate:** add `velocity_after_last_queue_item = 0;` inside
`clear_the_queue_and_stop_no_disable_interrupt()` (mirrors what the simulator init
already does).

**Workaround (documented in error_codes.json entry 16):** send 'System reset'
after an emergency stop during motion before queueing new moves.

### BUG-2: Multimove stack buffer overflow when moveCount > 32

**Component:** `firmware/Src/main.c`, `MULTIMOVE_COMMAND` handler
**Symptom:** a size-consistent Multimove packet declaring more than 32 moves is
`memcpy`'d into a fixed 260-byte stack buffer (sized for 32 moves) **before** the
`n_moves > MAX_MULTIMOVES` check runs — the copy at main.c:673 precedes the check
at main.c:678. The stack is smashed before `fatal_error(ERROR_MULTIMOVE_MORE_THAN_32_MOVES)`
can fire. Behavior after that is undefined (crash, corruption).

**Fix candidate:** validate `n_moves_in_this_command <= MAX_MULTIMOVES` (and that
`payload_size` is consistent with it) *before* the `memcpy`.

### BUG-3: 'Test mode' value 0 hangs the device (documented as "clear all test modes")

**Component:** `firmware/Src/main.c`, `TEST_MODE_COMMAND` handler
**Symptom:** sending 'Test mode' with value 0 routes into `set_led_test_mode(0)`
(main.c:880-883), which disables all interrupts, disables the MOSFETs, and enters
`while(1)` (main.c:178-188) **before the success response is sent**. The device
goes completely dead on the bus; only a power cycle recovers it. The historical
documentation said "0 = clear all test modes", which is exactly the value a
well-meaning user (or AI) would send.

**Related:** LED test modes 10-13 send the success response, then enter the same
interrupts-off `while(1)` forever — also power-cycle-only recovery. If that is
intended for production LED testing it should at least not disable the ability
to exit; consider making them time-limited or resettable.

**Fix candidate:** make value 0 clear `test_mode` (and not enter the LED-test
path); the safe clear today is only 'System reset'. The new motor_commands.json
description warns about this loudly, but the firmware behavior itself remains.

---

## Firmware — medium priority

### BUG-4: `ADD_TO_QUEUE_TEST` (opcode 120) desyncs the motion planner

**Component:** `firmware/Src/motor_control.c` `add_to_queue_test()` (:1802-1897)
**Symptom:** the debug command runs the full validation math and then **commits**
`velocity_after_last_queue_item` and `position_after_last_queue_item`
(:1888-1889) without queueing anything. Every later real move is validated from
this fictitious baseline (same failure class as BUG-1). It also sets
`ran_the_add_to_queue_test`, which suppresses the position-discrepancy check
(:2037-2041) but not the velocity check. Exposed over RS485 to anyone.

**Fix candidate:** compute the predictions into locals and do not commit them to
the planner state (or restore the previous values afterwards).

### BUG-5: int64 overflow hole in queue-time velocity prediction

**Component:** `firmware/Src/motor_control.c` `add_to_queue()` (:1727-1731)
**Symptom:** `predicted_final_velocity = velocity_after_last_queue_item +
acceleration * n_time_steps` can wrap int64 with pathological inputs
(acceleration up to ~2^34.75 internal units × n_time_steps up to 2^32-1 →
~1.2e20 > INT64_MAX). A crafted (accel, n) pair passes the final-value check
while the per-tick runtime accumulation crosses `max_velocity` and trips fatal
error 16 mid-move. Requires an absurd command (hours-long full-acceleration
move), so it is a validation hole rather than a normal-operation hazard.

**Fix candidate:** saturating/checked multiply, or bound `n_time_steps` per item.

### BUG-6: Divide-by-zero family

1. `compute_trapezoid_move()` divides by 0 when `duration == 0`
   (motor_control.c:453-456) — reached from 'Go to position' / 'Trapezoid move'
   with duration 0. On this platform the int64 software division returns 0 and
   the move becomes a silent no-op, but it is relying on undefined behavior.
2. `set_max_acceleration(0)` is accepted without error; any subsequent
   trapezoid-planned command then computes `max_velocity / max_acceleration`
   with a zero divisor (motor_control.c:449).
3. 'Get debug values' computes `averageHallPositionDelta` by dividing by a
   sample count that is zero if no samples accumulated since the last read
   (motor_control.c:1579-1581) — the read also resets the stats (:1585-1588),
   so two back-to-back reads always hit this.

**Fix candidates:** reject duration 0 / acceleration 0 with a parameter error,
or early-out; guard the average division.

### BUG-7: 'Get status' flags are stale in the fatal-error state

**Component:** `common_source_files/error_handling.c` (:90-101)
**Symptom:** in the fatal-error state, Get status is answered by the minimal
handler which returns the *stored* device_status without recomputing flags; the
flags are frozen at whatever the last normal-mode Get status computed (or 0 if
never queried since boot). Example: fatal_error() disables the MOSFETs, but the
"MOSFETs enabled" bit can still read 1. Only `fatalErrorCode` is trustworthy in
that state.

**Fix candidate:** clear (or recompute) the flags field inside `fatal_error()`
when the error code is stored.

---

## Firmware — minor / review-and-decide

- **Broadcast inconsistencies.** Most success-response commands execute on
  broadcast and only suppress the reply. Exceptions found: 'Control hall sensor
  statistics' skips the *action* too (main.c:750-764 — everything inside
  `if(!is_broadcast)`); 'Time sync' parses but never calls `time_sync()` on
  broadcast (main.c:390-400) — an AI told to "sync 10x/second" that broadcasts
  gets silently zero synchronization; 'Get communication statistics' never
  resets counters on broadcast (main.c:1114-1122). Decide which of these are
  intended and align the rest.
- **'Capture hall sensor data' responds even when broadcast** — the handler has
  no `is_broadcast` guard (main.c:301-360), so broadcasting it with multiple
  devices causes bus collisions. It also blocks ALL packet processing until the
  capture completes (main.c:1431-1434), with no abort mechanism.
- **Vibrate (M1 only): 'vibrate 0' faults if the queue is non-empty** — the
  queue check (:1176) runs before the turn-off branch (:1179), so even turning
  vibration *off* can raise fatal ERROR_QUEUE_NOT_EMPTY.
- **Temperature conversion clamps to 0 outside ~33..307 °C**
  (temperature.c:27-46) — a motor at room temperature reads exactly 0 °C, and
  the i16 can never go negative. A range sentinel distinct from 0 °C would be
  less misleading.

---

## Library / tooling bugs

### BUG-8: `counts_per_timestep` velocity conversion factor is wrong (~104.86×)

**Component:** `autogeneration/autogenerate_unit_conversions.py:289` →
`python_programs/servomotor/unit_conversions_M3.json` → Arduino
`AutoGeneratedUnitConversions.h/.cpp`
**Symptom:** the generator assigns `'counts_per_timestep': rps_factor`
(109951162.7776) instead of 2^20 = 1048576. Commanding a velocity in the unit
literally named `counts_per_timestep` sends ~104.86× the intended speed or trips
fatal error 16. Cross-check: `counts_per_second` = 33.554432 × 31250 = 1048576
is correct, and the acceleration variant `counts_per_timestep_squared` =
16777216 = 2^24 is correct — only the velocity one is wrong.
**Fix:** one line in the generator, then regenerate `unit_conversions_M3.json`
and the Arduino unit-conversion files (both Python and Arduino libraries are
affected).

### BUG-9: M3.py wrapper time-unit conversion ~32× off (known, TODO #8)

Verified during this effort: the wire format of 'Get current time' / 'Time sync'
is true microseconds (TIM14 at 1 MHz; no conversion in the handlers), and the
JSON `InternalUnit: microseconds` is correct. The ~32× discrepancy therefore
lives in the Python wrapper's conversion layer (the conversion-factors file uses
the 32 µs timestep as the internal time unit: `timesteps: 1`,
`microseconds: 0.03125`), i.e. the M3 wrapper applies timestep-based factors to
microsecond-based wire values for these commands. Already tracked as TODO #8.

### Minor tooling items

- `python_programs/convert_python_motor_commands_to_json.py` writes the key
  `"data_type_id:"` (trailing colon); if ever re-run it would emit a
  `data_types.json` the loader cannot read. Stale legacy generator.
- `unit_conversions_M3.json`'s header says "modify autogenerate_unit_conversions.py"
  but the copy next to it exists only as `.bak`; the live generator is
  `autogeneration/autogenerate_unit_conversions.py`.
- Generated Arduino file banners cite `generate_command_code_new2.py`, which no
  longer exists (the orchestrator runs `generate_command_code.py`). Cosmetic.
- `Get comprehensive position`'s third output (`externalEncoderPosition`)
  carries a position `UnitConversion`, but it is a raw external quadrature count
  (EXTI counter on PB4/PB5, GPIO_interrupts.c:36-65); applying motor position
  units to it yields meaningless values. Removing the metadata changes the
  generated Python/Arduino APIs — needs a decision. (The prose now explains it.)

---

## Documentation drift (non-firmware, found during the repo survey)

- `servomotor_datasheets/package.txt` still uses stale "M3-60/M3-48/M3-40" model
  names and a height spec inconsistent with `specs.py`.
- `marketting_page/specs.py` rated power (38/32/25 W) disagrees with
  `servomotor_datasheets/specs.py` (26.4/26.4/24 W) — the two spec sources drifted.
- `API_documentation/servomotor_api_documentation.pdf` (Aug 2025) is superseded
  by the M17-split docs and should probably be moved to `.bak`.

---

## Added 2026-07-10 (from Tom's documentation review + bench measurements)

### BUG-10: Library default time unit is 'timesteps'; should be 'seconds'

**Component:** `python_programs/servomotor/M3.py` (defaults come from the first
entry of each units list in `unit_conversions_M3.json`)
**Symptom:** `M3(alias)` without `time_unit=` interprets all durations as 32 µs
timesteps — `trapezoid_move(1.0, 2.0)` means 2 timesteps, not 2 seconds. Tom:
the default should be seconds. (The Arduino library already defaults to SECONDS.)
**Fix candidate:** explicit default `time_unit='seconds'` in the M3 constructor
(safer than reordering the JSON units list, which would change the generated
Arduino enums' first entry / documentation of internal units).

### BUG-11: Reading an empty multipurpose buffer gets no response

**Component:** `firmware/Src/main.c` READ_MULTIPURPOSE_BUFFER_COMMAND handler
(entire transmit path inside `if (data_type != 0)`)
**Symptom:** the host times out (1.2 s) and must treat TimeoutError as "buffer
empty". Tom: this is a bug — the device should respond.
**Fix candidate:** send a response with data_type 0 and no payload when empty.

### BUG-12: M3 constructor does not parse 16-hex-digit unique-ID strings

**Component:** `python_programs/servomotor/M3.py` (~lines 311-329)
**Symptom:** `M3("0123456789ABCDEF")` raises ValueError (or, worse, an all-digit
ID string is silently misparsed as decimal), even though the constructor's own
error message mentions hex strings. `communication.string_to_alias_or_unique_id()`
already implements the correct parsing.
**Fix candidate:** use `string_to_alias_or_unique_id()` inside the constructor.

### BUG-13: M3 wrapper methods have no CRC32 control

**Component:** `python_programs/servomotor/M3.py`
**Symptom:** high-level methods always append a CRC32; after `crc32_control(0)`
the wrapper can no longer talk to the device — users must drop to
`execute_command(..., crc32_enabled=False)`.
**Fix candidate:** a per-object flag (e.g. `motor.set_crc32_enabled(False)`)
threaded through to execute_command.

### BUG-14: Receive-buffer flush after detection should be automatic

**Component:** `python_programs/servomotor/` (detection / command layer)
**Symptom:** users currently must call `servomotor.flush_receive_buffer()` after
device detection or risk stale bytes corrupting the next response parse.
**Fix candidate:** flush inside detect_devices()/detect_devices_iteratively()
after the response-collection loop completes (and possibly before every
send_command when the RX buffer is unexpectedly non-empty).

### BUG-15 (investigated 2026-07-15 — NOT REPRODUCIBLE on current firmware/library/bench)

Evidence from the investigation session (fw 0.15.4.0, current library, single M17
on /dev/cu.usbserial-210 with adapter-motor ground connected):

- Dedicated stress harness: 3 minutes of aggressive random velocity segments
  (up to ±6 rot/s, motor current 390) while hammering get_status / get_position /
  ping with no inter-read sleeps: **49,360 reads, 729 motion segments, ZERO
  failures**, and all six device-side communication counters (CRC32, decode,
  first-bit, framing, overrun, noise) read 0 afterwards.
- `test_random_speed_stress.py` run twice end-to-end: PASSED both times with no
  retry paths firing.

Conclusion: the "this step is unreliable" comments date from older
firmware/library revisions (before the receive-buffer flush and related fixes)
and possibly a different bench configuration (multiple motors, or no ground
between adapter and motors). If read failures ever reappear, the first
diagnostic is 'Get communication statistics' — nonzero framing/noise/CRC
counters point at the electrical path; clean counters with host-side timeouts
point at the firmware response path. The retry loops in the two stress tests
are harmless and were left in place.

### BUG-15 original report: occasional read failures under stress implied by tests

**Component:** unknown (firmware RS485 path, library parsing, or USB adapter)
**Evidence:** `test_random_speed_stress.py` retries get_status in up to 5 passes
with the comment "I found that this step is unreliable", and
`test_get_temperature.py` retries reads 3x. Tom: this should not be true; likely
a bug. Bench validation of the 47 examples saw zero failures under light load.
**Action:** reproduce under high-speed motion + polling, capture the failing
bytes, and determine whether the loss is firmware-side (e.g. TX while busy),
library-side, or adapter-side.

### BUG-16 (docs/comments): LED "communication traffic" indicator is GREEN, not red

**Truth (confirmed in firmware + by Tom):** `common_source_files/RS485.c:454-460`
lights the GREEN LED while a packet is being received. The red LED is the
fatal-error blinker (plus an M1/M2-only overcurrent indicator).
**Stale artifacts to fix:** the code comment at RS485.c:454 still says "control
the red LED"; `servomotor_datasheets/indicators.py` still tells users the red
LED shows communication traffic (the datasheet PDF therefore documents the old
behavior). PROTOCOL_SPEC.md already says green and is correct.

### Bench measurements affecting documented timings (not bugs)

- Post-'System reset' minimum quiet wait: 0.5 s is sufficient (bootloader window
  is at most ~250 ms); the 1.5 s used across the test suite is just margin.
- Post-'Set device alias' wait: device answered in application mode at the new
  alias 0.3 s after the command on the bench; docs now say 0.5-1 s.
- Broadcast 'Time sync' no-op CONFIRMED by experiment (30 broadcast syncs: clock
  rate unchanged within 161 ppm; same 30 addressed: shifted ~6800 ppm).
- Confirmed by Tom as wanted fixes: BUG-6 (accel-0 / duration-0 validation) and
  BUG-7 (status flags frozen in fatal-error state).

---

## Added 2026-07-16 (hands-on exploration session, fw 0.15.4.0 on the bench)

Full experiment narrative in `EXPLORATION_LOG_2026-07-16.md` (E15 covers the
lock-up, E16 the fix verification).

**STATUS UPDATE 2026-07-16 (later): BUG-17/18/19/20 ALL FIXED in firmware
0.15.5.0** (built, flashed to the bench motor after Tom power cycled it, and
hardware-verified):
- BUG-17/19: `fatal_error()` now hand-drains any in-flight reply before the
  fatal loop runs (new bounded `rs485_drain_transmit()` in RS485.c; MOSFETs
  are still disabled FIRST, per Tom's priority) and suppresses the deferred
  error reply when a reply was already issued (flag now cleared at every
  reply-issuing point in RS485.c, closing the desync window); the fatal
  loop's response path is also guarded against transmit-busy.
- BUG-18: `Set safety limits` rejects lower > upper with fatal error 34.
- BUG-20: System reset in the fatal state always sets `reset_requested`
  (executes once TX drains) even when the reply must be skipped.
- Verification on hardware: 10/10 inverted-limit sends -> clean FatalError 34
  with readable status (this exact sequence previously truncated/hung);
  15/15 rounds of fatal-45 firing during continuous get_status traffic ->
  clean error delivery, zero timeouts, zero desyncs; sequential
  status-then-reset in fatal state works. NOTE: a "pipelined" two-packets-in-
  one-write test fails by design — this is a half-duplex bus, so the second
  request collides with the first reply on the wire (captured collision
  garbage confirms); not a firmware defect.
- Also compile-verified against the bootloader target (shared files) and the
  simulator (MOTOR_SIMULATION) flags. The c_test_programs simulator Makefile
  itself is PRE-EXISTINGLY broken (hardcodes -DPRODUCT_NAME_M3, rejected by
  gpio.h) — unrelated to this change, flagged for later.

### BUG-17 (CRITICAL): async fatal error during reply transmission hard-hangs the device — power cycle required

**Component:** `common_source_files/error_handling.c` fatal loop +
`common_source_files/RS485.c` transmit path.
**Symptom:** if a fatal error fires from the 32 µs motor-control ISR while a
command reply is still draining out of the UART, the reply is truncated
mid-packet and the device goes permanently silent: Get status, ping, System
reset (addressed, broadcast, and unique-ID) are all ignored. Only a power
cycle recovers it. This violates the documented guarantee that Get status and
System reset are always answered in the fatal-error state. Reproduced on the
bench: `set_safety_limits(2.0, -2.0)` (inverted bounds, see BUG-18) makes
fatal 25 fire within one 32 µs tick of the success reply starting to
transmit; three runs produced three different outcomes (clean error packet /
truncated reply but functional fatal state / truncated reply + hard hang)
depending on the interleaving.
**Root cause (chain of three):** (1) `fatal_error()` executes `__disable_irq()`
while `transmitCount > 0`, stalling interrupt-driven TX with a partial packet
on the wire (only what already sat in the 8-deep UART FIFO drains — hence the
intermittency). (2) `main.c` sets `if_fatal_error_then_respond_flag` at
command start and clears it only at the end of `process_packet` (main.c:1145),
so the flag is still set. (3) The fatal loop's first action
(`systick_half_cycle_delay_plus_handle_commands`, error_handling.c:123-126) is
`rs485_transmit_error_packet()` with NO transmit-idle guard and BEFORE any
manual `USART1_IRQHandler()` pump — `rs485_transmit()` enters
`while(transmitCount > 0);` (RS485.c:481) which can never decrement with IRQs
off. Infinite spin; RX dead; reset command unreachable.
**Suggested fix:** in `fatal_error()` before the loop (or in the flag branch),
manually pump `USART1_IRQHandler()` until `!rs485_transmit_not_done()` (with a
timeout), or abort TX (`transmitCount = 0` + flush FIFO) before transmitting
the error packet. Defense in depth: enable the independent watchdog (IWDG) so
any future deadlock self-recovers.
**Exposure:** any ISR-raised fatal (25, 41, 45, 16, ...) landing in a ~300-500 µs
reply-TX window. Rare for genuinely asynchronous errors, but BUG-18 makes it
nearly deterministic.

### BUG-18: 'Set safety limits' accepts inverted bounds (lower > upper), guaranteeing fatal 25 one tick later

**Component:** `firmware/Src/main.c` SET_SAFETY_LIMITS handler (no validation),
`firmware/Src/motor_control.c:2557-2560` (per-tick check).
**Symptom:** sending lower=2.0, upper=-2.0 stores the values unvalidated; with
lower > upper EVERY position is outside the zone, so the ISR check
`(pos > upper || pos < lower)` raises fatal 25 within 32 µs — racing the
command's own success reply, i.e. directly arming BUG-17. Observed all three
BUG-17 outcomes from this one trigger, including the hard hang.
**Suggested fix:** validate `lower <= upper` in the handler and reject with an
error response instead of storing; also consider validating that the CURRENT
position is inside the new zone.

### BUG-19: unsolicited error packet after a completed reply desynchronizes the host

**Component:** `firmware/Src/main.c` flag lifetime + fatal loop response.
**Symptom:** when a fatal fires in the microseconds after a command's reply
was fully sent but before `if_fatal_error_then_dont_respond()` (end of
`process_packet`), the fatal loop transmits an EXTRA error packet that the
host never asked for. The host library then reads this stale packet as the
reply to its NEXT command, shifting every subsequent response by one packet
(observed on the bench as a FatalError raised against the wrong command and a
subsequent partial-read timeout).
**Suggested fix:** clear the respond-flag immediately after each handler
queues its reply (not at the end of `process_packet`), or record a
"reply already sent" marker the fatal loop checks. Library side (defensive):
`flush_receive_buffer()` before transmitting each command would self-heal
one-packet desyncs.

### BUG-20 (code inspection, not yet hardware-verified): System reset silently dropped in fatal state while a reply is draining

**Component:** `common_source_files/error_handling.c` `handle_packet()`
SYSTEM_RESET branch.
**Symptom (predicted):** in the fatal-error state, a System reset that arrives
while the previous reply (e.g. a Get status response) is still transmitting is
completely ignored — `reset_requested` is never set because the whole action
sits inside `if ((payload_size == 0) && !rs485_transmit_not_done())`. A host
that pipelines get_status + system_reset back-to-back never gets the reset and
sees a timeout. Same pattern in the GET_STATUS branch (dropped status reads).
**Suggested fix:** set `reset_requested = 1` unconditionally (the reset
already waits for TX-done before executing); only the reply transmission needs
the busy guard. Could not be hardware-verified because BUG-17 hung the bench
motor first.

### BUG-21 (FIXED in 0.15.6.0): 'Set maximum velocity' accepts 0, silently turning every position move into a no-motion dwell

**Fix status (2026-07-16):** fixed in firmware 0.15.6.0 — `set_max_velocity()`
now rejects 0 with fatal 34, mirroring the BUG-6 pattern in
`set_max_acceleration()` (its only caller is the command handler, so no
internal path is affected). Hardware-verified: 3/3 clean FatalError 34 with
readable status and normal recovery; tiny nonzero limits still accepted;
motion regression clean. `test_set_maximum_velocity.py` gained a
zero-rejection scenario (passes). Docs rescoped in motor_commands.json,
error_codes.json (error 34 trigger list), and knowhow.

**Component:** `firmware/Src/motor_control.c` `set_max_velocity()` (:3259, no
validation) + trapezoid planner.
**Symptom:** after `set_maximum_velocity(0)` (accepted with a success reply),
every 'Trapezoid move'/'Go to position' is accepted, occupies the queue for
the commanded duration, returns success — and moves NOTHING: the commanded
position never advances and no error is ever raised (verified on 0.15.5.0,
hall and commanded both frozen). 'Move with velocity' correctly rejects with
fatal 16. The velocity twin of the fixed maxA=0 hole (BUG-6), but it fails
SILENTLY instead of crashing. Reachable by accident: the library rounds any
requested limit below half an internal unit down to 0.
**Suggested fix:** reject 0 in the SET_MAXIMUM_VELOCITY handler with fatal 34
(ERROR_PARAMETER_OUT_OF_RANGE), matching the 0.15.4.0 treatment of
'Set maximum acceleration' 0.

### BUG-22 (root cause confirmed by Tom; docs fixed): 'Test mode' 4 (GC6609 register dump) is defunct on current hardware

**Update 2026-07-16:** Tom confirmed the GC6609 chip is no longer used. The
M17 scc>=2 build includes AT5833.h instead (motor_control.h product/scc
gate), so the `#ifdef GC6609` mode-4 code is compiled out entirely — the
command stores nothing and test_mode stays latched at 4 until reset. Docs
updated to mark mode 4 defunct. Suggested cleanup (not yet done): remove or
scc-gate the mode-4 path and the stale "make sure to uncomment" comments;
consider an AT5833 register-dump equivalent if production still needs one.

**Component:** `firmware/Src/motor_control.c` TIM16 handler GC6609 branch
(:2995-3002) / `GC6608_UART_bit_bang_read_registers`.
**Symptom:** after test_mode(4), 'Read multipurpose buffer' returns the empty
tag forever (polled 10 s, MOSFETs enabled and disabled, fw 0.15.6.0 bench
M17) — the bit-bang register read never reports finished, so
MULTIPURPOSE_DATA_TYPE_GC6609_REGISTERS is never stored and test_mode stays
latched at 4 until reset. Docs claimed the dump works; doc caveat added.
Developer-facing severity (production/debug tool).
**Also observed:** switching to mode 4 while mode 3 is active corrupts the
pending read (mode-4 entry wipes the shared `multipurpose_data_size` while a
mode-3 dataset is still tagged → 1-byte tag-only response). Suggested fix:
investigate the bit-bang read's finished condition on M17 hardware 1.5, and
have set_motor_test_mode clear `multipurpose_data_type` when wiping the size.

### BUG-24 (FIXED in 0.15.9.0): 'Set max allowable position deviation' with INT64_MIN latched fatal 45 on the next tick

**Fix status (2026-07-20):** the handler in `firmware/Src/main.c` now
saturates INT64_MIN to INT64_MAX before the `llabs()` call, completing the
documented absolute-value contract (a maximal negative input now means a
maximal limit, the same value the boot default uses). Hardware-verified on
0.15.9.0: INT64_MIN accepted with no fatal 3/3 and behaves as
watchdog-at-maximum (a 3-rotation MOSFETs-off commanded advance no longer
trips); ordinary negatives keep the abs contract (-0.5 rot limit trips at
1 rot advance); default enforcement regression intact (2.01 rot trips 45).
Docs rescoped in motor_commands.json and error_codes.json.

**Component:** `firmware/Src/main.c:997` — `set_max_allowable_position_deviation(llabs(new_...))`.
**Symptom (hardware-verified 3/3 on 0.15.8.0):** the wire value INT64_MIN is
accepted with a clean success reply, but `llabs(INT64_MIN)` is undefined
behavior and stays negative on ARM, so the per-tick check
`llabs(position_deviation) > max_allowable_position_deviation`
(motor_control.c:3136) is true on every tick and fatal 45 latches
immediately. All other negative values take their absolute value as
documented. Recoverable with System reset; no lock-up (the 0.15.5.0
reply-race fix held under this brand-new trigger — clean success reply,
fatal delivered on the next command). Found 2026-07-20 while the doc-audit
fleet ran.
**Suggested fix:** special-case INT64_MIN (clamp to INT64_MAX) or reject it
with fatal 34 in the handler.

### BUG-23 (FIXED in 0.15.7.0): velocity/acceleration ceilings were 2x/4x their intended design values

**Fix status (2026-07-16, per Tom's ruling "default = actual motor maximum,
configurable higher for experiments"):** `TIME_STEPS_PER_SECOND` corrected to
`PWM_FREQUENCY` (the motor-control ISR runs once per PWM period; the stale
`>> 1` halved it), so MAX_VELOCITY/MAX_ACCELERATION now compute the rated
34 rot/s (2040 RPM) and 500 rot/s^2 and are the boot defaults. New
EXPERIMENTAL_MAX_VELOCITY (2x) / EXPERIMENTAL_MAX_ACCELERATION (4x = the
old effective limits) are used only in the set-command clamps, so
experimenters can still exceed the rating. Hardware-verified on 0.15.7.0:
boot readbacks exactly 34.00 / 500.0; limit settable to 39 rot/s and 1500
rot/s^2, clamped at 2000; predicted-36-rot/s move rejects with 28 at
default and runs after raising the limit; regression + suite velocity test
PASSED. Bonus wire-format facts documented: the u32 limit field caps
settable velocity at ~39.06 rot/s (so the 68 clamp is unreachable over the
wire) and move commands (i32) cap at ~19.5 rot/s.

**Component:** `firmware/Src/motor_control.h` MAX_VELOCITY / MAX_ACCELERATION
derivation chain.
**Symptom (hardware-measured, fw 0.15.6.0 M17):** boot-default max velocity
reads back 68.0 rot/s (4080 RPM) although the chain starts from MAX_RPM 2040;
boot-default max acceleration reads 2000 rot/s^2 although derived from
10000 mm/s^2 / 20 mm-per-rot = 500 rot/s^2. The silent clamp in
set_max_velocity/set_max_acceleration therefore also allows users 2x/4x the
intended envelope.
**Root cause area:** `TIME_STEPS_PER_SECOND` is defined as
`PWM_FREQUENCY >> 1` in the same header; for this product it evaluates to
half the true 31,250 steps/s control rate, inflating MAX_VELOCITY by 2x and
MAX_ACCELERATION (which divides by TSPS^2) by 4x. ONE_REVOLUTION_MICROSTEPS
(3,276,800) matches the encoder counts, ruling out a microstep-unit factor.
**Impact:** low at 20 V (physics caps at ~8.6 rot/s) but the envelope guard
is not protecting the design intent; the runtime fatal-16 check with boot
defaults only fires at 68 rot/s. Needs Tom's intent ruling: fix the macro
(halving the effective ceilings) may CHANGE behavior for users who relied on
the current defaults.

- **Trapezoid slot count:** 'Trapezoid move' description says "2 [items] if
  there is no coast phase" — measured: ALWAYS 3 items, even for triangular and
  zero-displacement (dwell) moves (E6). Also 'Get n queued items' output text
  still claims "Zero-duration moves are dropped silently" — zero-duration is
  now REJECTED with fatal 34 on ≥0.15.4.0.
- **Stale post-stop advice:** 'Emergency stop' / 'Reset time' descriptions
  still say to send 'System reset' before queueing further moves; verified
  unnecessary on ≥0.15.4.0 (E9) — rescope to older firmware.
- **Safety limits follow the zeroed frame:** 'Zero position' shifts the
  physical location of the safety fence (limits are interpreted in the current
  frame, E14a) — must re-send 'Set safety limits' after zeroing if the fence
  protects real hardware. Not currently documented.

---

## Already fixed during this effort (for context)

- `error_codes.json`: was missing `ERROR_STREAMING_OVERFLOW = 54`; all 55 entries
  rewritten from traced `fatal_error()` call sites and adversarially verified
  (original in `error_codes.json.bak`).
- `motor_commands.json`: all 48 command descriptions and 78 parameter texts
  rewritten from byte-verified firmware handlers (original in
  `motor_commands.json.bak`); structure/types/UnitConversion untouched.
- `API_documentation/autogeneration/error_handling.txt`: enriched with the
  verified fatal-error/LED semantics, communication statistics counters, and
  test-mode notes.

---

## STATUS UPDATE 2026-07-27 — Arduino library bugs FIXED + verified

All Arduino-library bugs below are **FIXED** (generator-side changes, then regenerated;
never hand-edited the generated files) and **verified on BOTH hardware targets** (ESP32-S3
bench + 35-motor rack), 63/63 tests, 1043 assertions, 0 failures:

| Bug | Fix |
| :-- | :-- |
| **BUG-25/26/27** (variable-length responses) | Generator now detects `size:null` output types and emits a CALLER-OWNED-BUFFER API: `void <cmd>([inputs,] buf, bufferSize, actualSize*)` — fail-fast guard on null/zero buffer (no bus traffic), strings null-terminated (actualSize = strlen), blobs raw, required size reported on `BUFFER_TOO_SMALL`. `Communication::getResponse` now reports the required size on too-small (it already drains the full packet). The 3 fixed-size response structs were removed. |
| **BUG-28** (32× time) | Generator is now `InternalUnit`-aware: microsecond-wire time params (cmd 9 Get current time output, cmd 10 Time sync input) are scaled by `CONVERSION_FACTOR_MICROSECONDS` at the conversion call site. Timestep-based move durations unchanged. |
| **BUG-29** (new, default units) | Arduino default units are now data-driven = the first unit listed per type in `unit_conversions_M3.json` (matching Python). Current default AMPS→`internal_current_units`; voltage list reordered so both libraries default to `volts` (firmware internal unit is decivolts / volts×10 — confirmed in ADC.c). |

The test suite's 8 formerly-failing "expected-fail" assertions now PASS; those tests'
known-bug annotations were cleared so any regression is flagged as unexpected.

---

## Arduino library — variable-length response bugs (found 2026-07-21)

Found while validating the Arduino library after the doc/codegen work (multi-agent
static audit + regenerate-and-diff + hardware confirmation). **NOT fixed yet — logged
for a later fix session.** All three share ONE root cause and are pre-existing generator
limitations, not regressions.

**Root cause:** `autogeneration/generate_command_code.py` emits, for EVERY command response,
a fixed-size C++ struct plus a `receivedSize == sizeof(struct)` **exact-match** check. That
is wrong for response fields whose data type is **variable-length** (`string_null_term`,
`general_data`, both `"size": null` in `data_types.json`). The firmware returns a payload
whose length is not `sizeof(struct)`, so the equality check always fails, the method sets
`COMMUNICATION_ERROR_DATA_WRONG_SIZE` and returns a zeroed/empty struct. The command can
never deliver its data on Arduino. The **Python reference library handles these correctly**
(`communication.py` ~747-816: null-terminator search for `string_null_term`, actual-length
read for `general_data`).

| Bug | Command | JSON output type | Generated struct | Runtime result on Arduino |
| :-- | :--- | :--- | :--- | :--- |
| **BUG-25** | cmd 24 Get product description | `string_null_term` | `char[32]` (Servomotor.h:149) | firmware sends 11 B `"Servomotor\0"` → `11 != 32` → always `DATA_WRONG_SIZE`, returns empty. Empirically confirmed: Python returns `[['Servomotor\x00']]`; Arduino `getProductDescription()` never succeeds. |
| **BUG-26** | cmd 7 Capture hall sensor data | `general_data` (stream) | `uint8_t data` (1 B, Servomotor.h:66-69) | multi-point capture is `nPoints*channels*2` bytes → never `== 1` → can never receive the capture. |
| **BUG-27** | cmd 35 Read multipurpose buffer | `general_data` | `uint8_t bufferData` (1 B, Servomotor.h:217-220) | variable buffer contents → exact-1-byte check fails → always empty. |

**Impact:** none are core motion/telemetry, so all runtime motion tests still pass; these are
informational/diagnostic reads that are silently non-functional on Arduino.

**Suggested fix (later):** teach `generate_command_code.py` to detect null-size data types and
emit a variable-length receive path — a large/bounded buffer, accept `receivedSize <= bufsize`,
and (for `string_null_term`) null-terminate — mirroring the Python `communication.py` logic.

**Verification also done 2026-07-21 (no bugs):** regenerate-and-diff of the command code showed
the committed `Servomotor.cpp`/`.h`/`Commands.h` are byte-identical to generator output for the
current JSON across all 48 commands, except `//` description comments + timestamp (0 functional
diffs). The datasheet Arduino example compiles verbatim for ESP32-S3 and runs correctly (moves
exactly 1.0 rotation).

## Arduino library — BUG-28: 32× time error for microsecond-wire commands (found 2026-07-21)

Found by the expanded Arduino test suite (new `test_ard_time.cpp`) and confirmed against the
Python library on the same motor. **NOT fixed yet — logged for later.**

**Symptom:** the Arduino `getCurrentTime()` reads **32× too large** in every time unit (over a real
1 s sleep it reported 32.36 s); `timeSync()` puts a value **32× too small** on the wire. The Python
library reads the same device correctly (seconds≈1.0, µs≈1e6, timesteps≈31250).

**Root cause:** the Arduino code generator is NOT `InternalUnit`-aware. It routes every `Type=="time"`
parameter through one generated `convertTime()` whose table is normalized to **timesteps** (31250 Hz,
`CONVERSION_FACTOR_SECONDS=31250`). Two parameters actually have `InternalUnit=="microseconds"` (1 MHz)
on the wire, so they are off by exactly `1,000,000 / 31,250 = 32×`. The Python library fixes this via
`M3.py` `_rescale_for_internal_unit` (keys factor tables on `Type_InternalUnit`); the Arduino generator
has no equivalent. Root-cause locations: `autogeneration/generate_command_code_module/maps.py`
(`UNIT_CONVERSION_MAP` maps Type→func only, ignores InternalUnit), `generate_command_implementations.py`
(emits `convertTime` keyed on Type only), `generate_unit_conversion_code.py` (single timestep table).

**Scope — exactly two parameters** (all 48 commands enumerated):

| Bug | Cmd | Param | Dir | InternalUnit | Effect |
| :-- | :-- | :---- | :-- | :--- | :----- |
| **BUG-28a** | 9 Get current time | `currentTime` | Output | microseconds | reads 32× too large |
| **BUG-28b** | 10 Time sync | `masterTime` | Input | microseconds | sent 32× too small (huge timeError) |

All timestep-`InternalUnit` time params (move durations: Trapezoid/Go-to-position/Homing duration,
Move-with-velocity/acceleration timing, Multimove) are CORRECT — verified by passing motion tests.
`updateFrequency` (raw Hz) and capture `timeStepsPerSample` (raw timesteps) carry no UnitConversion and
are unaffected. **Suggested fix:** make the Arduino codegen `InternalUnit`-aware (mirror Python's
`_rescale_for_internal_unit`), then regenerate.

## Arduino test-suite expansion (2026-07-21)

Added 14 new host-emulator `test_ard_*.cpp` files (~250 assertions) mirroring the Python per-command
tests, covering ~all 48 commands. Run against the bench M17 (uid 99856389A2B46555) via an ESP32-S3
USB↔RS485 bridge. Everything passes EXCEPT the four known bugs above (BUG-25 product description,
BUG-26 capture hall data, BUG-27 read multipurpose buffer, BUG-28 time). Motion, settings, safety,
PID, closed-loop, homing, addressing/set-alias, CRC32 control, detect, status, telemetry, diagnostics,
vibrate/identify/test-mode all correct. (One initial homing failure was a test-only unit-clobber bug,
fixed; homing library code is correct.)

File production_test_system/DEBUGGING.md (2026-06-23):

# Debugging a hang / livelock (runbook)

Read this first if the test system **wedges**: the UI/detection is stuck, a bus
shows `running` forever, "1 detection queued" never clears, or the machine fans
spin up (high CPU). This happened once — three bus-worker threads spun at 100%
CPU and we had **no way to see what they were doing** (macOS SIP blocks
`py-spy`/`lldb` from attaching to the Xcode-Python the venv is built on) and **no
durable logs** (the in-memory log had drained). The mechanisms below exist so
that never happens again. They are always on and add no meaningful overhead.

## When it's wedged, do this (in order)

1. **Get the thread stacks — the single most useful action.** HTTP stays
   responsive even when the workers are wedged:

   ```
   curl http://localhost:8000/api/debug/stacks
   ```

   This prints every thread's Python stack. Find the three `bus-A/B/C` threads:
   whatever file:line they sit on **is the bug**. (Also saved to the durable log,
   see below.)

2. **Check the durable log** for what led up to it (worker phase transitions,
   errors with full tracebacks, and one `VITALS` line per minute showing CPU and
   per-bus state over time):

   ```
   curl http://localhost:8000/api/debug/log?lines=400
   #   ...or read the file directly (survives restarts):
   #   data/diagnostics.log   (and data/diagnostics.log.old after rotation)
   ```

   If the watchdog already saw the high-CPU signature it will have **auto-dumped
   the stacks into this log** (`WATCHDOG ALERT ...`) — so the evidence may
   already be captured even before you ran step 1.

3. **Backup stack dump without HTTP** (SIP-immune, no attach, no sudo). Find the
   server PID and signal it; stacks are appended to `data/faulthandler.log`:

   ```
   lsof -nP -iTCP:8000 -sTCP:LISTEN -t           # -> PID
   kill -USR1 <PID>
   tail -n 200 data/faulthandler.log
   ```

4. **Quick health probe** (machine-readable): `curl http://localhost:8000/api/debug/vitals`

**Capture stacks BEFORE restarting.** A restart fixes the symptom but destroys
the evidence. Grab steps 1–3 first, then restart to recover.

## What's installed (see `backend/diagnostics.py`)

- `GET /api/debug/stacks` — all-thread Python stacks on demand.
- `GET /api/debug/log` / `GET /api/debug/vitals` — durable log tail / health.
- `data/diagnostics.log` — durable log: app/worker events (teed from the app
  log), full exception tracebacks from bus workers, one `VITALS` line/minute, and
  any watchdog auto-dumps. Rotates at ~16 MB to `.old`.
- **Watchdog thread** — logs vitals every 60 s and, on **sustained high CPU**
  (≥1.5 cores for ~3 min — the livelock fingerprint), auto-dumps all stacks to
  the durable log. A false trigger (e.g. a long PNG-generation burst) only costs
  one extra dump in the log; it never interferes with a run.
  **Limitation:** the auto-dump triggers on CPU only, so it **misses a zero-CPU
  deadlock** — a worker blocked in a syscall (the 2026-06-05 wedge below sat at
  `cpu_cores=0.01`). A "stuck" trigger (a bus `run=True` with an unchanged phase
  and no DB write for N minutes) would catch that class; until it exists, grab
  `GET /api/debug/stacks` manually the moment a bus stalls. The `VITALS` lines
  still record the stall even with no auto-dump.
- **`SIGUSR1` faulthandler** — `kill -USR1 <pid>` dumps all stacks to
  `data/faulthandler.log`. Works while a thread is spinning in a C extension
  (sqlite3) and needs no debugger, so it bypasses the SIP restriction.

All of this is observational only — it never kills threads, cancels work, or
touches the RS485 bus.

## Incident 2026-06-05 — Phase 11, Bus B wedge (root cause CONFIRMED)

A Phase 11 (thermal) run wedged on **Bus B**: 8 motors stuck "collecting"
(yellow), bus idle, adapter LEDs dark. Reconstructed from the durable
`data/diagnostics.log` `VITALS` trail (no live stacks — the process had already
exited, and the watchdog never auto-dumped because CPU was ~0):

- Buses A and C finished Phase 11 cleanly (`run` flipped to `False` at 15:36 /
  15:38); Bus B stayed `run=True ph=11` from ~15:35 until the process died at
  16:00, **`cpu_cores=0.01` the whole time**, `threads=6` constant → a **zero-CPU
  blocked syscall**, not a spin.
- **No exception/error line was ever logged** during the run → not a
  `SerialException` disconnect (`bus_worker` would have logged "phase N error
  (continuing)") — a *silent* block.

**Root cause:** `SerialTransport.__init__` opens the port with a read `timeout`
but **no `write_timeout`** (pyserial default `None` = block forever). Reads are
bounded; `self._ser.write()` (`transport.py`) is the only unbounded blocking
call. When Bus B's USB-RS485 adapter stopped draining its TX buffer (adapter
hang / USB re-enumeration), the per-second `Get temperature` write parked the
worker thread permanently. The motors were fine (they overheated → fatal, and
still answer the bus). This is exactly the disconnect-intolerance the fix below
targets (item 1). Full evidence preserved at
`data/incidents/diagnostics_2026-06-05_phase11_busB_wedge.log`.

## Note on the original (2025) incident — root cause still unknown

The trigger was **not** reproducible by yanking the adapters during Phase 9
(Phase 9 is ~5 s; the operator does not unplug mid-test). The symptoms were
*different* from the 2026-06-05 wedge above: three bus workers pegged at 100% CPU
spinning in **SQLite reads** (no DB writes, no serial I/O), state frozen at
`running / phase 9`, holding stale serial fds from before a USB re-enumeration,
with a detection queued behind the stuck run. If it recurs, `GET /api/debug/stacks`
will show the exact loop immediately — paste that output to pin the root cause.

## The fix (deferred — item 1 now confirmed by the 2026-06-05 wedge)

Only diagnostics were added so far. The 2026-06-05 incident confirms the
**disconnect intolerance** below is real (item 1, the missing `write_timeout`,
was the exact root cause); the 2025 livelock may need items 2–4 as well. The
hardening, roughly in order:

1. **Detect the disconnect.** Open the serial port with a `write_timeout` (it is
   currently `None` in `transport.py:SerialTransport.__init__` → a `write()` to a
   vanished FTDI can block forever), and treat `OSError`/`serial.SerialException`
   as a **fatal bus error** that aborts the current job instead of being swallowed
   as a generic `Exception`.
2. **Guarantee cleanup on every exit path.** Ensure `bus_worker._run_sequence`
   (and `_run_detect_passes`) always reset `running`/`detecting`/`pending_detections`
   and `close()` the transport in `finally`, even on a hard serial fault — so the
   queue never wedges behind a stuck job and stale fds are not leaked.
3. **No unpaced loops.** Whatever loop the dump implicates: give it a wall-clock
   cap and a mandatory minimum sleep so an instantly-failing serial call (dead fd
   returns immediately, defeating the read timeout) can never spin a core.
4. **Tolerate USB re-enumeration.** A replug gives the adapter a new device node;
   detect a stale fd and reopen the port by path before a job (each job already
   calls `_open_transport`, so the main gap is not getting *stuck* in the old one).

Add a regression test that simulates a mid-run serial disconnect (raise from the
transport) and asserts the run aborts cleanly with flags reset and the queue
drainable.

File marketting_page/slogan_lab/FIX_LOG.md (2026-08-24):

# Slogan transition bug hunt — overnight 2026-08-23/24

Tom's brief: the transitions have bugs. Two named symptoms — the background flashes white when it
should be black, and a transition sometimes fails to start or end on the canonical text position and
size. Fix as many as possible before 06:00; he rates all 96 in the morning.

## How the bugs are found

`audit_frames.py` drives `_frameaudit.html`, whose stage is a byte-for-byte copy of the rater's.
The engine already makes every effect a pure function of progress `t`, so a frame is *asked for*
rather than caught: `_render(t)` for a list of t values, one element screenshot each.

Per effect, per slogan pair, it measures

| metric | what it catches |
|---|---|
| `startSnapBox` / `endSnapBox` | ink bounding box at t=0.008 / t=0.992 vs the canonical frame, in px — Tom's "doesn't start/end at the canonical position and size" |
| `startSnapCov` / `endSnapCov` | fraction of the stage that visibly differs from the canonical frame |
| `flash` | fraction of the stage gone near-white — Tom's white flash |
| `blankFrames` | headline absent mid-transition |
| `errors` | a throw inside `frame()`, which freezes the animation and reads as a dull effect |

The ink box is measured from PIXELS, not the DOM. Asking the DOM is the obvious approach and it is
wrong: effects build two full-stage layers, so the union of their client rects is the whole stage
regardless of what is visible.

Calibration: known-good effects (`wipe-bar`, `light-specular`) score 0.0000 on every endpoint
metric, so the thresholds in `audit_report.py` sit just above anti-aliasing noise.

## Baseline, before any fixes

96 effects, 2 slogan pairs each. **34 clean, 62 with defects.**

    START-SNAP=83  END-SNAP=73  START-DIFF=71  END-DIFF=31
    FLASH=20       START-VANISH=18  END-VANISH=16

## Round 1 — two root causes, 30-odd effects

### 1. The white flash: effects painting a paper sheet over a dark stage

Seven effects painted an opaque light sheet for the *entire* transition, so the stage went
black → white → black every cycle: `glitch-tear`, `glitch-mosh`, `glitch-blocks`,
`liquid-goo-merge`, `print-riso`, `print-tear`, `dissolve-chromatic`. Three more painted white
faces: `depth-cube`, `depth-flip`, `depth-unfold`.

The three glitch effects were the worst of it — they painted a near-white sheet but never set a
text colour, so the headline inherited the stage's light ink and was nearly invisible on its own
paper.

**Fix — the sheet is not white, the sheet is whatever the stage already is.** `engine.js` gained
`stageColors()`, which walks up from the stage to the first non-transparent background, and hands
every effect `ctx.sc` = `{ dark, paper, ink, raised, sunken, edge, shade() }`. Effects now take
their sheet from `ctx.sc.paper`. This also makes the rater's "On white" toggle honest: the same
effect re-mounts as dark ink on white paper instead of needing a second hard-coded palette.

`print-riso` and `dissolve-chromatic` needed more than a colour swap. Both are *subtractive* print
metaphors — spot inks multiplying down onto white paper — and multiply has no meaning on a dark
ground. They now flip to `screen` on a dark stage, and `dissolve-chromatic` also flips the blend
*identity* (multiply's is white, screen's is black), which its two-beat inking depends on. The
misregistration, the re-inking and the walk back into alignment are unchanged; only the direction
of the ink changes.

Result: flash 100% → 3-5%, which is the canonical frame's own coverage. All ten also went to
0-2px on both endpoints as a side effect.

### 2. The 45px jump: a `<br>` between two block halves

17 effects were off by *exactly* 45px at both ends. One cause. The engine forces a lone
`.fx-light`/`.fx-bold` pair to `display:block` for the canonical two-line rest state; a `<br>`
between two blocks then opens an anonymous **third, empty line box**, so the effect's layer sat a
line looser and higher than the canon and the headline jumped a whole line the instant the effect
took over.

Seven effect files already carried a comment warning about exactly this. Seven others still had the
bug — 16 sites across `house-extra.js`, `house-extra-2.js`, `print.js`, `kinetic.js`, `slide.js`,
`depth.js` and `_reference.js`.

Twelve were the simple shape (two spans and a `<br>`) and were fixed by codemod: both halves become
`display:block`, the `<br>` goes. Four were structural — `kinetic`, `slide` and `depth` tag
individual *words* `.fx-light`/`.fx-bold`, so the engine's two-line enforcement deliberately skips
them and the `<br>` was the only row separator. Each half now gets its own block row, the way the
canonical layer does it. Every caller passed `split: true`, so the one-line branch was dead code
and is gone.

### 3. Incidental

`print-tear` built its torn piece with a hand-rolled inner that had both the `<br>` bug and a
trailing space, in a file whose own helper carries the warning comment. Its torn fibre was a
72%-white streak, which is right on paper and a glare on a dark stage; it now uses `ctx.sc.shade()`.

## Round 1 result

**34 clean → 51 clean.** FLASH went from 20 occurrences to zero. START-VANISH 18 → 6.

## Round 2 — the 11-12px breath, and why the obvious fix was wrong

After round 1 the largest remaining group was ~22 effects, every one of them off by 11-12px at the
start and 7-8px at the end, and only on slogan pair 12. Same centre, same y, same height — the line
was simply **wider** while the effect owned the stage, so the headline breathed outward about 6px a
side on entry and back in on exit.

**A wrong turn, recorded because the reasoning looked sound.** Pair 12 is the long slogan, so the
first hypothesis was wrapping: `words()` and `charWords()` separate words with a
`white-space: pre` span, and `pre` cannot collapse at a line break, so a wrapped line would render
one extra space. Changing those to plain collapsible text nodes changed nothing (still 11-12px) and
regressed `type-backspace` at pair 0 from clean to 25px. Reverted. Measuring the DOM afterwards
showed why the premise was false: the canonical box is 797px wide, which is the natural width of
the longest row — **the line never wraps at all.**

**The real cause: kerning.** Almost every effect animates per word or per character, which means
each one gets its own inline-block. A glyph in its own box cannot kern against its neighbour, so a
split line renders wider than the identical text as a single run — a consistent 11-12px on a 797px
line, about a quarter of a pixel per glyph. The canonical layer is one plain run, and it *does*
kern.

There is no way to make a split line kern. So the fix runs the other way: stop the plain run
kerning too. `engine.js` now sets `font-kerning: none; font-variant-ligatures: none` on the stage,
which both layers inherit. Both renderings then agree to within a pixel, and the cost is a
sub-pixel looseness at 46px that nobody can see standing still — where the 12px jump was obvious.

This belongs on the stage, not in each effect: the canonical layer has to agree with whatever the
effect does, so both have to be told the same thing from one place.

Measured across the whole cluster afterwards — shatter, liquid, type, slide, glitch, print, hy-smoke
— **0-2px on every endpoint, 24/24 records under threshold**, and the two calibration effects that
were already perfect (`wipe-bar`, `light-specular`) stayed at 0.0.

## Round 3 — the per-effect geometry bugs, fanned out by file

Thirteen effects still had real geometry faults, from 25px up to 706px, plus three that drew
*nothing* at the endpoint frames. These are individual bugs with individual causes, so they were
fanned out one agent per effect FILE (files, not effects, so no two agents ever edited the same
file), each given the audit tooling, the canonical contract, and the two root causes already fixed
so it would not chase them again. Every group was then re-audited by a second agent that was told
not to trust the first one's numbers.

| file | fixed |
|---|---|
| `house-extra.js` | hx-riso, hx-rgb-split, hx-tear (all three re-implemented), hx-spotlight, hx-neon-flicker, hx-signal-lock |
| `house-extra-2.js` | hy-vernier (650px), hy-dimension-line (330px), hy-origami (re-implemented), hy-louvre |
| `mechanical.js` | mechanical-slide-rule (706px), mechanical-split-flap (425px), mechanical-typewriter (316px), mechanical-dot-matrix, mechanical-flip-cards |
| `light.js` / `print.js` / `kinetic.js` | light-shadow (241px), print-inkjet (302px), kinetic-pendulum (126px) |
| `_reference.js` / `type.js` | odometer (75px), type-backspace (25px) |

All five verifiers reported the claims accurate, `node --check` clean, and **no regressions** — each
re-audited every effect in its files, not only the ones that were touched.

The verification went past the endpoint numbers, which was the right instinct: an effect can satisfy
"looks like canonical at both ends" by simply doing nothing in between. One verifier wrote its own
mid-transition probe measuring colour saturation and stage coverage across t, and confirmed that
`hx-riso`'s spot ink and `hx-rgb-split`'s channels really do render mid-transition (saturation peaks
0.41 and 0.79, falling to 0.01 at the endpoints) rather than having been quietly suppressed.

**Two things a metric cannot judge, flagged for Tom's eye:**

- `hy-origami` is a genuine mechanism change, not a repair. It no longer flips 180° to a back face;
  it folds edge-on and back with the text swapped at the crease. It is contract-clean, but it looks
  different from what it was.
- `hx-spotlight` is contract-clean but its beam easing leaves roughly the first fifth and last fifth
  of the transition as still frames. A rater may read that as a slow start rather than a bug.

## Where round 3 landed

**96 of 96 effects clean** at pairs 0 and 12 — no endpoint snap, no flash, no vanish, no blank
frames, no thrown errors.

Residual deviation across all 192 records: ink box **median 1px, worst 3px**; visible coverage
difference median 0.9%, worst 3.4%. That is anti-aliasing scale, well under what an eye catches on
a 46px headline.

    baseline   34 clean / 62 defective
    round 1    51 clean / 45 defective   (paper palette, <br>)
    round 2    73 clean / 23 defective   (kerning)
    round 3    96 clean /  0 defective   (per-effect geometry)

## Round 4 — three angles the endpoint audit cannot see

Passing the endpoint check is necessary, not sufficient: an effect could satisfy it by doing
nothing in between, or by being different every time it runs. `audit_extra.py` asks three other
questions of all 96 effects.

**INVARIANCE — 0 failures.** This is Tom's actual requirement, stated back in the design phase: "a
given text will always appear the same no matter what". So render the canonical frame for the same
slogan under all 96 effects and demand the images are identical. All 96 agree to within
0.0008 mean absolute difference. Any effect that leaked a style onto the stage, or drew its own
idea of the rest state, would show here. None do.

**DETERMINISM — 0 failures.** Render the same t twice from a fresh mount and demand the same
pixels. Nothing uses `Math.random()` or the clock, so a screenshot, a GIF export and the live page
cannot disagree.

**CONTINUITY — 1 real fault, 1 false positive.** Walk t in 40 steps and flag any step far larger
than that effect's own typical step.

- `light-neon` alternates 0.057 / 0.000 steps in a square wave. That is a neon tube flickering; it
  is the effect, not a bug. Left alone.
- `liquid-goo-merge` had a genuine pop: one step of 0.036 at t=0.157 against a background of
  0.005, a 7x jump in the middle of an otherwise smooth melt. Cause: the filter was switched
  between `'none'` and `blur(...) contrast(...)` at a threshold. Toggling `filter` is not a no-op
  even at near-identity values — it creates and destroys a stacking context, so the box is
  re-rasterised and the type shifts a fraction of a pixel. The filter is now applied for the whole
  transition at identity values when the melt is weak. Step 0.061 -> 0.039, ratio 6.1x -> 3.5x,
  which is unremarkable (the 90th percentile across all effects is 9.2x).

The same `filter = cond ? blur(...) : 'none'` idiom appears about twenty times across the set, but
only this one crossed a visible threshold, so the others were left alone rather than churned.

**A false alarm worth recording.** Three effects — `ink-bleed`, `dissolve-develop`, `hy-lens-focus`
— looked motionless: their largest frame-to-frame step was under 0.004. Measuring total travel
instead showed they cover 82-123% of the distance between the two canonical frames, which is the
same as `wipe-bar` (123%). They are smooth, not dead. Low frame-to-frame delta is a virtue here,
not a symptom, and "fixing" them would have damaged three working effects.

## Round 5 — what only the other twelve slogan pairs could show

Pairs 0 and 12 were chosen for the audit because one is short and one is the longest. That was not
enough. Sweeping all fourteen found three more faults, all of them invisible on the two pairs that
had been tested all night.

**`wipe-columns`, up to 334px off at the start.** The clip helper `pctPad(v)` ramps its padding
compensation from +0.26em at v=0 to **−0.26em** at v=100, so "fully hidden" put the clip edge at
the glyph's bottom rather than at the bottom of the box, leaving the empty bottom padding
unclipped. That was harmless right up until you notice `frame()` also translates the inner span
down by up to 0.16em — which walks real glyph pixels into that supposedly empty strip. The
*incoming* line was showing as a sliver from the very first frame, so the measured ink box spanned
both slogans at once. Worst on the pairs whose two texts differ most in width, which is exactly why
pairs 0 and 12 hid it. The pad now ramps to zero, so hidden means hidden: **334px → 2px** across
all fourteen pairs.

**`glyph-scramble` and `print-letterpress`, 8-13px, on the same six pairs.** Both build their rows
from `alignWords`, which pads the word LIST as well as the letters — a four-word slogan morphing
into a seven-word one leaves groups that are entirely blank at one end. Both effects already
collapsed those groups to zero width. Neither collapsed the **space in front of them**, and on a
centred line two or three phantom spaces drag the whole row sideways. The inter-word gap is now a
cell like any other, with its own two sides, so it collapses with the group it introduces.

That fix alone made `glyph-scramble` worse at the far end, which turned out to be a second,
independent bug hiding behind the first: its stagger ran `lead` 0 → 0.55 with a 0.45 window, so the
first cell began churning at t=0 and the last settled at exactly t=1.0. The first effect frame was
already showing a random glyph instead of the outgoing character, and the last was still showing
one instead of the incoming character — and substitute glyphs are not the width of the letters they
stand in for. The stagger now starts at 0.04 and is done by 0.95.

    wipe-columns       334px -> 2px   (all 14 pairs)
    glyph-scramble      13px -> 1px   (all 14 pairs)
    print-letterpress   13px -> 2px   (all 14 pairs)

The lesson worth keeping: two slogan pairs is not a sample. Every one of these three needed a pair
where the two texts differ in *word count*, and neither pair 0 nor pair 12 does.

## Round 6 — a narrower stage

The rater is a fixed 1100px box and every slogan except the longest fits on one line there. The
hero is responsive, so the same effects have to survive a width where more of them wrap. Re-running
the audit with the stage at 680px found three faults that 1100px cannot show.

**`type-backspace`, 53px at the start and 66px at the end.** It hid untyped characters with
`display:none` and, because that reflows, locked each row to its measured width and left-aligned
the text inside. Correct at 1100px, where nothing wraps. At 680px the long slogan wraps and the
effect left-aligned each wrapped line while the canonical layer centred it. It now hides characters
with `visibility` instead, so the block always occupies its fully-typed layout — same width, same
height, same wrap points, first frame to last — which lets the rows stay `text-align: center` like
the canon, and makes the width lock unnecessary. Typing looks the same; it reveals rather than
inserts. **53/66px → 0px**, and still 0-1px at 1100px.

**`kinetic-gravity`, 6.3% of the stage out at the end.** Its incoming bounce ran `span(t, lead, 1)`
— the window closed at exactly t=1, so at t=0.992 `outBounce` had not quite reached 1 and every
word was still a fraction above its resting place. At 1100px that was a 3px residual, the worst in
the set; at 680px the long slogan runs to more lines and the residual multiplies across them. The
bounce now lands at 0.96. **≤3px at both widths.** (Same shape of bug as `glyph-scramble`'s
stagger in round 5: a schedule that uses the whole of 0..1 leaves no room to be *finished* in.)

**`depth-flip`, 21px at the end — NOT FIXED, and deliberately so.** At 680px the leaf's own copy of
the incoming text wraps differently from the backing layer's copy, so the two halves of the fold
disagree and 1065 pixels of the settled frame sit outside the canonical text. It is contract-clean
at 1100px, the width Tom rates at. Fixing it means restructuring how a 3D fold shares one text
layout across four faces, which is not something to attempt speculatively at 01:30 on an effect
that currently works. Recorded here so it is not mistaken for a passing effect.

## Round 7 — depth-flip, isolated rather than guessed

`depth-flip` was the one defect left, 21px at 680px only, and two rounds of reading the code did not
explain it: the leaf is an opaque full-width sheet hinged on the centre line, it lands at 180
degrees, and it ought to cover the outgoing bottom half completely.

Rather than keep theorising, the four surfaces in the scene were hidden one at a time at t=0.992 and
the ink box measured each time. Hiding the outgoing bottom-half layer — and only that — reproduced
the canonical frame exactly. So the leaf's own back face was already carrying the incoming bottom
half correctly; the old copy underneath simply was not covered, because at 680px the long slogan
wraps, the block is taller, and the fold no longer reaches it at the very end.

The outgoing bottom half now fades out over the last 30 degrees of the fall. It cannot affect any
earlier frame, because until then it sits behind an opaque leaf either way. **21px → 1px at 680px,
unchanged at 1100px.**

The general lesson, twice over tonight: when the code says a thing should be covered and the pixels
say it is not, stop reading and start removing surfaces one at a time.

## Round 7 verification

    canonical invariance   0 failures   all 96 render a pixel-identical rest state
    determinism            0 failures   no Math.random, no clock
    continuity             1 flagged    light-neon, which is a flicker on purpose
    thrown errors          0

---

# Final state

Every number below is from a run made after the last code change, not carried forward.

| sweep | records | result |
|---|---|---|
| 96 effects x all 14 slogan pairs, 1100px (the rater's width) | 1344 | **96 clean, 0 defects** |
| 96 effects x pairs 0 and 12, 680px (a width where the long slogan wraps) | 192 | **96 clean, 0 defects** |
| canonical invariance / determinism / continuity, 96 effects | 288 | 0 / 0 / 1 (`light-neon`, a deliberate flicker) |

Residual deviation across the 1344-record run — this is what "clean" actually means here:

    ink box offset at the endpoints    median 1px   p95 2px   worst 4px
    visible difference from canonical  median 0.7%  p95 1.8%  worst 4.3%
    frames brighter than canonical     worst +8.7%  (mid-transition, no full-stage flash anywhere)
    thrown errors                      0

For scale: the headline is 46px type on a 1100px stage, so a 1-2px endpoint offset is anti-aliasing,
not something an eye catches. At the start of the night the worst offender was 706px.

## The arc

    baseline   34 clean / 62 defective
    round 1    51 clean / 45 defective   paper palette, <br>
    round 2    73 clean / 23 defective   kerning
    round 3    96 clean /  0 defective   per-effect geometry (16 effects, 5 agents)
    round 5    3 more found by sweeping all 14 slogan pairs, all fixed
    round 6    3 more found at 680px, 2 fixed then, 1 in round 7
    round 7    depth-flip, isolated by removing surfaces one at a time

## Four root causes accounted for most of it

Three were single fixes that repaired whole clusters, and are worth remembering because each one
had already been found and fixed *somewhere* in this codebase and then not applied everywhere:

1. **A `<br>` between two `display:block` halves** opens an empty third line box. Seven effect files
   carried a comment warning about it. Seven others still had the bug — 17 effects, all off by
   exactly 45px.
2. **Effects painting their own white paper** onto a stage that is nearly black. The sheet is not
   white; the sheet is whatever the stage already is. `engine.js` now derives it.
3. **Per-character inline-blocks cannot kern**, so split text is wider than the same text as one
   run. Since a split line cannot be made to kern, the plain run stops kerning instead.
4. Everything else was individual: a clip helper computing a negative inset, a schedule that used
   the whole of 0..1 and so had no room to be *finished* in, a filter toggled rather than ramped,
   a phantom space in front of a collapsed word group.

## What is deliberately NOT changed

- `light-neon` flickers in a square wave. That is the effect.
- The 96 GIFs in `gifs/` are from 21 August and predate all of this. `gallery.html` is the only
  page that reads them; `rate.html` mounts the live effects, so the rating tool is current.
- Nothing outside `slogan_lab/` was touched. `final/index.html` and the store are untouched, as
  instructed — the shipped page still carries the engine as it was.

## Two judgement calls a metric cannot make

- `hy-origami` was re-implemented rather than repaired: it no longer flips 180 degrees to a back
  face, it folds edge-on and back with the text swapped at the crease. Contract-clean, but it looks
  different from what it was.
- `hx-spotlight` is contract-clean, but its beam easing leaves roughly the first fifth and last
  fifth of the transition as still frames. That may read as a slow start rather than a bug.

## The tools, if this needs doing again

    python3 audit_frames.py --pairs 0,12            # endpoints, flash, blanks, throws
    python3 audit_frames.py --quick --pairs 0,1,..  # thinned mid-probes, for sweeping many pairs
    python3 audit_frames.py --width 680             # a width where the long slogan wraps
    python3 audit_extra.py                          # invariance, determinism, continuity
    python3 audit_report.py _audit/<file>.json      # ranked defect list

`_frameaudit.html` is the harness; its stage is a copy of `rate.html`'s, so what it measures is what
Tom sees. Change one, change the other.

---

# Round 8 — the rater's "On white" toggle

`rate.html` has an **On white** button. Everything above was measured on the dark stage, so the
light one was an entirely untested surface. Auditing it found the *mirror image* of the night's
first bug.

**First, the metric was wrong.** The initial white run reported all 96 effects flashing, which is
nonsense. "Flash" was defined as the fraction of the stage gone near-white — and on a white stage
the canonical frame is already 97% near-white, so every frame trips it. The measure now asks the
question Tom actually asked: does the **ground** change colour? It compares each frame's median
colour against the canonical frame's median colour. Validated both ways before trusting it — 0.000
on the repaired `glitch-tear`, and 0.939 when the old white sheet was forced back in for one mount,
against a 0.25 threshold.

With that fixed: 88 of 96 clean on white. After the four dark-sheet repairs below, **92 of 96**.

**Four effects hard-coded a DARK sheet** — `glitch-lock`, `glitch-crt`, `glitch-rgb`,
`liquid-mercury` — which is a black flash on a white stage, exactly the same mistake as the white
paper on a dark stage, pointing the other way. All four now take `ctx.sc.paper`. Verified on both
stages: ground shift 0.00-0.04 everywhere, and nothing on the dark stage regressed.

**Three effects legitimately vanish on white, and are deliberately left alone.** `light-neon`,
`light-bloom` and `dissolve-luminance` are built on additive light: `mixBlendMode: 'screen'`, white
halos, `rgba(255,253,244, …)` ink. White is screen's identity, so on a white ground they compose to
nothing. This is the same shape as the subtractive-print problem that `print-riso` and
`dissolve-chromatic` needed solving in round 1, and the fix is the same in reverse — flip to
`multiply` with dark ink when `ctx.sc.dark` is false. That is a genuine re-implementation of three
effects, and they are pixel-perfect on the dark stage, which is the one being rated. Not worth
doing speculatively at 03:30. **Known limitation, written down rather than half-fixed.**

`mechanical-dot-matrix` also differs by 15-20% on white (its dot rendering does not resolve to
plain text there). Same category, same reasoning.

---

# Morning state, 06:00

| check | result |
|---|---|
| 96 effects x 14 slogan pairs, dark stage 1100px (the rater) | **96 clean / 0 defects**, 1344 records |
| 96 effects x 2 pairs, dark stage 680px (wrapping width) | **96 clean / 0 defects** |
| 96 effects x 2 pairs, white stage (the "On white" toggle) | **92 clean / 4 known**, listed below |
| canonical invariance / determinism / thrown errors | 0 / 0 / 0 |
| continuity | 1 flagged: `light-neon`, a deliberate flicker |

Worst residual on the rated stage: ink box 4px, median 1px, on 46px type.

`rate.html` checked end to end at 06:00: 96 effects registered, stage `rgb(10,11,12)`, kerning
disabled, all three buttons present, ratings still cleared, headlines cycling, no console errors.

The four that are not clean on white, all understood and all perfect on the dark stage:

| effect | why |
|---|---|
| `light-neon` | additive light — `mixBlendMode: 'screen'`, and white is screen's identity |
| `light-bloom` | same |
| `dissolve-luminance` | same |
| `mechanical-dot-matrix` | its dot rendering does not resolve to plain text on a light ground |

The fix for all four is the reversal that `print-riso` and `dissolve-chromatic` already got in
round 1: flip to `multiply` with dark ink when `ctx.sc.dark` is false. It is a real
re-implementation of four effects and was not worth doing speculatively overnight.

The 96 GIFs in `gifs/` were re-exported from the fixed effects.

---

# Round 9 — Tom's verdicts, 2026-08-24

All 96 rated: **81 keep, 11 discard, 4 fix**. The four flagged for fixing carried no notes, so the
defect in each had to be found by looking. They all PASSED the frame audit, which is the point —
these are faults the endpoint metrics cannot see.

Looking meant `strip.py`, a new tool that stacks the frames of one transition into a single tall
image **as the rater draws it**. `filmstrip.html` could not be used: it applies each effect's
`theme`, and `rate.html` deliberately does not ("the page owns the palette, an effect owns only the
motion"), so a filmstrip shows an effect in monospace on cream paper that Tom saw in the page's own
sans on near-black.

**`type-find` — the type was being mangled.** Each replacement word was scaled horizontally to fit
the slot of the word it replaced, `clamp(a.w / b.w, 0.52, 1.85)`. An 85% stretch turns "one motor."
into a different, much heavier face; a 48% squeeze makes "The" look like a condensed cut. Half the
transition was set in fonts the page does not own. Removing the scale alone makes words collide,
which is why it was there — so instead each word now **re-justifies as it swaps** rather than the
whole line re-justifying at the end. The line is then only ever ragged at the boundary between the
part already replaced and the part not yet reached, which is what an editor doing a find-and-replace
actually looks like.

**`mechanical-typewriter` — a caret adrift on an empty stage.** During the carriage return the old
line has rolled away and the first key has not struck, and a bar of ink slid across the middle of a
blank stage attached to nothing. It now fades through the crossing, leaving the end of the old line
and arriving at the head of the new one.

**`liquid-mercury` — two faults.** The melt used `sin(pi*t)^1.35`, already at half strength by
t=0.2 and not back under it until t=0.8, so a *global* blur+contrast smeared the whole line for two
thirds of the transition — unreadable white worms. That contradicted the effect's own design note,
which says only a slice is ever molten: the per-cell wave was working, a global filter was melting
everything regardless. A gaussian centred on the swap is spent by t~0.25 and t~0.75. Separately the
contrast was dragging the near-black ground to pure black for the length of the transition; the
ground is now pre-distorted by the inverse of the contrast so the filter lands it exactly back on
the stage colour. Both goo effects got that treatment.

**`type-backspace` — the headline vanished, and a regression of mine.** The erase finished at
t=0.34 and the retype did not begin until t=0.39: 0.13s during which the entire headline was gone
and the only thing on the hero was a blinking caret. Closed to a single frame.

The second fault was mine, from the night before. I had changed it to hide characters with
`visibility` so the block keeps its settled layout — and `visibility: hidden` is the one form of
hiding a DESCENDANT can override. Every typed character setting `visibility: visible` reappeared
through the engine's hidden layer, so at t=1 the effect's own text and caret were drawn on top of
the canonical frame: 0.8% of the stage, including a caret the canon does not have.

**The engine now closes that hole for good.** `_showCanon` sets the layer to `opacity: 0` as well as
`visibility: hidden`. A parent at opacity 0 cannot be overridden from inside, and unlike
`display: none` it keeps the layer laid out, so effects that measure their own geometry still can.
Only one effect was exploiting the gap, but any future one could have.

After all four: every endpoint back to **0.0000% difference from canonical**, and a full re-sweep of
all 96 at pairs 0 and 12 still **96 clean / 0 defects**.

## Shipping Tom's decisions

`build_page_engine.py` rebuilds the engine inlined in `final/index.html` from `slogan_lab/`, reading
the verdicts out of `ratings/transitions.json`. It drops the `FX.register({...})` block of every
discarded effect by brace matching — a regex cannot, since effect bodies contain braces inside
strings, comments and regexes — and rewrites the cycler's POOL to exactly what was kept. Helper
functions of discarded effects stay, because they are often shared with kept ones; only the
registration goes, so the effect can never be picked.

Result: **85 registered, 85 in the pool, none of the 11 discards present**, verified in a browser.
The page's inlined engine grows 118 KB -> 430 KB, which is the honest cost of keeping 85 effects.

---

# Round 10 — Tom's three comments, and a check that would have caught them

His notes came back in the rater's `why` field (not `note`, which is why the first read showed them
empty). `liquid-mercury` passed. Three left:

**`type-find`** — "the yellow highlight, I would like it if it were green instead to go with my page
better." Now Gearotons green `#7AB648`. Switching it made a second thing obvious: a word being
DELETED has no replacement to ride the re-justify with, so its selection stayed parked at its old
slot while the line closed up around it — a lone block of colour past the end of the new line. Pale
yellow hid that; brand green did not. It now fades out with the word it is deleting.

**`type-backspace`** — "the letters drop by about a pixel after the transition." They did, and it
was a real 1px, not a rendering artefact: shifting the last effect frame down one pixel fitted the
canonical frame better than not shifting it. The cause was the caret. It is a zero-WIDTH caret, but
not a zero-HEIGHT one: sitting on the baseline at `vertical-align:-0.19em` it hung below the row's
descender and grew that line box by 1.05px. The block is flex-centred, so one row a pixel taller
lifted the whole headline a pixel above the canonical text. Top-aligned it is shorter than the strut
and cannot grow the box, and `position:relative` puts it back where it looked right — a relative
offset is painted, not laid out. The effect's block is now 115.32/99.36, the canon's 115.32/99.36,
to the hundredth of a pixel.

**`mechanical-typewriter`** — "the letters move by about a pixel... would be better if they just
were typed out one by one accurately in their final position." The per-letter misalignment that
makes a struck line look hand-set rather than typeset was being applied permanently: `_dy` and
`_rot` stayed on every glyph at rest, so each letter finished a fraction off the canonical position
and the line twitched as a whole when the engine took over. The jitter now rolls off to nothing as
each letter settles, exactly as he asked. Residual 0.00427 -> 0.00260, which is *below* `wipe-iris`,
an effect nobody has complained about.

## A new check, because he found this twice and the audit did not

`audit_frames.py` now measures **the settle**: the last effect frame (t=0.999) against the canonical
frame it hands over to, plus a shift test — if the residual drops when the frame is moved a pixel,
it is a real positional error rather than anti-aliasing. That is precisely what he was seeing, and
the endpoint checks at t=0.008/0.992 were too coarse to catch it.

Running it over all 96 found the same fault in **nine more effects**, eight of them a true -1px:

- The whole **depth family** (cube, flip, hinge, dolly, helix) shared one cause: `equalize()` rounded
  the block height to a whole pixel, but two 49.68px rows are 99.36, so the block came out a third
  of a pixel short of the canon and the flex centring put it in the wrong place. It now uses the
  measured fractional height. All five clean.
- **`odometer`** and **`kinetic-gravity`** are still out at pair 12 only. An attempt to snap the
  odometer's drum travel to whole pixels made it *worse* — its cell geometry is in em throughout and
  a px translate fights it — so that was reverted rather than left as a half-fix. Both are recorded
  here rather than shipped as fixed.
- **`mechanical-split-flap`** and **`wipe-blinds`** also show it, and both are effects Tom discarded,
  so they never reach the page.

**92 of 96 clean under the new, stricter check**; of the 85 that actually ship, 83.

## A build guard that misfired, and shipped the wrong thing for one deploy

`build_page_engine.py` treated "the POOL substitution came back identical" as a failure. On a
rebuild where the pool has not changed that is the NORMAL case, so it aborted, left the page
carrying the previous engine — and the deploy that ran straight afterwards happily shipped it. It
now fails only if the POOL line is absent. Caught by diffing the deployed bundle for the fixes it
was supposed to contain, which is a check worth keeping in the habit.

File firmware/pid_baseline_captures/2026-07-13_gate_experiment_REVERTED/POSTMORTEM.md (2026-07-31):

# Zero-crossing gated integral (fw 0.15.4.0–0.15.4.2): REJECTED AND REVERTED

**Date:** 2026-07-13. **Outcome:** reverted to the committed 0.15.3.4. Nothing from
0.15.4.x ships. **Read this before attempting the "full torque at small error" goal again.**

## What we were trying to solve

Tom's requirement: the motor should apply *maximum torque even when the position error is
tiny* (0.1% of a revolution = 3,277 counts), the way a classical integrator would — wind up
until the error is gone. The 25% integral clamp shipped in 0.15.3.4 (the anti-windup that
cured the kI>10 limit cycle) caps sustained torque at ~31% of stall at that error, so the
motor parks short under load (measured: 1,991 counts short at current 25 — see plan §17).

## What we built (and why it looked right)

A **zero-crossing-gated integral**: the integral may exceed the 25% rail toward *full*
authority once the error has kept one sign (outside a ±1,000-count deadband) for 0.1 s;
on each zero crossing it is set to the midpoint of its last two crossing values (self-tunes
to the true hold torque, since the stick-slip friction band is symmetric about it) and
integration freezes for 0.1 s.

It passed *everything we could measure*:
- Load holding: standing error 9.3k → ~600 counts in sim; **on the bench, a 0.1%-rev step
  that 0.15.3.4 parks 1,991 counts short of converged to 1 count** (integral reached 317%
  of the old rail). The stated goal was objectively achieved.
- Snap overshoot, no-load quiet, dormancy, release behavior: all within budget.
- Differential 7.0M samples bit-exact, UBSan overflow 3×1.42B ticks clean, battery/sweep
  green, ISR cost ≤1–2 µs, mutation testing killing every planted defect.

## Why it failed — the thing no test caught

**Tom's hand.** With the gate active he felt, at every tuning tried: a **whine/vibration**
when holding the shaft slightly off-position, and **jerkiness/notchiness** when rocking the
shaft through the setpoint. Decisive experiment: **at kI=0 (integral and gate machinery
inert) all complaints vanished instantly** — smooth, quiet, no overshoot — but the return
became weak/slow and parked short. So the roughness *is* the gate machinery, not the
mechanics, not the D term, not the disk.

Two repair attempts, both instructive:

1. **Slew-limited corrections (0.15.4.2).** Diagnosis: crossings reassigned the integral
   *instantly* — up to a full rail-to-rail torque reversal in one 32 µs tick. Fixed by
   slewing (one-tick |ΔI| 103M → 6.6M, bound airtight). **Bench verdict: no better.**
   Lesson: a 0.5 ms ramp and a 32 µs step are indistinguishable to a human hand. Smoothing
   at tick timescales cannot fix a feel problem that lives at 0.1–1 s timescales.
2. **Above-rail windup rate cap (designed, never flashed).** Adversarial verification
   **broke it before hardware**: the cap equilibrates against the back-calculation drain and
   silently pins holding torque at ~68% of rail for loads ≥ 0.26 N·m (parks ~8° off,
   permanently, 10/10 seeds). Do not resurrect a wind cap without solving that interaction.

Also tried and rejected on the bench: kI=5 (slower integral tempo) — still bad.

## The real lesson (the one to keep)

**The gate makes the loop's behavior depend on interaction history.** Its state machine
(same-sign counter, crossing midpoints, freeze windows, staleness) operates on exactly the
timescales a human hand works at — 0.1–1 s — so a hand interacting with the motor
continuously re-triggers it: the integral winds against the hand, crossings fire corrections,
freezes gate the response, and the torque *trend* keeps shifting under the fingers. That is
felt as whine and notchiness, and it is **structural to any state-machine-gated integrator**,
not a tuning or smoothing defect. Our entire validation suite measured *hands-off* scenarios
(steps, profiled moves, constant loads, releases) and every one of them passed; the failure
mode lived in a dimension we never instrumented — and even after we *did* instrument it
(forced-rock/forced-hold sim scenarios with per-tick torque-smoothness metrics), the metric
we chose (per-tick ΔI) turned out to be the wrong proxy for what a hand perceives.

**If this goal is attempted again, do not re-derive this design.** Directions that do NOT
carry the same flaw, in rough order of promise:

1. **Feedforward, not gated feedback.** The torque needed to hold a load is a *plant*
   property, not a control-history property: estimate it (e.g. a slow, unconditional
   low-pass of the output during steady state) and add it as a feedforward term. No state
   machine, no history dependence, no crossing events — the smoothness problem cannot arise.
2. **Raise the honest ceiling instead of gating.** The 25% clamp exists because integral
   torque above breakaway friction re-arms the stick-slip limit cycle (I-rail torque 0.094
   N·m vs 0.13 N·m breakaway — plan §17). Reduce the *stiction* (mechanics) or reduce the
   integral's *stick-slip coupling* (e.g. integral acting only below a velocity threshold)
   and the clamp can rise safely without any gating.
3. **Accept the standing error and fix it at the trajectory level** — profiled moves already
   land clean; the error only appears against sustained external loads.
4. **Velocity-based D with int64 math** (plan §21) — orthogonal, still promising for
   heavy-inertia loads, unrelated to this failure.

## Bench truths worth keeping (independent of the gate)

- **Return speed law:** cruise speed ≈ authority/kD counts/tick — kD is simultaneously the
  landing brake *and* a cruise governor. "Fast return + soft landing" cannot be tuned
  independently with fixed PID gains.
- **Braking window:** the PID error input is clamped at authority/kP, so the loop is blind
  to distance beyond it; that clamp is also the emergent brake trigger (widening it made
  overshoot 5× worse — plan §21). Lowering kP is the per-load knob.
- **Heavy inertia:** commanded snap moves are ballistic (J·ω²/2τ); at 20× rotor inertia a
  0.2-rot snap overshoots 18° at *any* gains, while the same move over 0.2 s overshoots
  0.05°. Trajectory shaping, not tuning.
- **Fleet caution:** the 25% clamp's quiet margin depends on breakaway friction; sim says
  units with stiction ≤ 0.10 N·m could hum even at 25%. Unmeasured across the fleet.

## Artifacts preserved here

- `rejected_source/` — the full 0.15.4.2 firmware (`motor_control.c.bak`, `main.c.bak`),
  the complete firmware diff, the gated simulator, and the harness-mirror diffs.
- `rejected_firmware_binaries/` — all 0.15.4.x `.firmware` builds (M17 + M23), moved out of
  `firmware_releases/` so they can never be flashed by accident.
- Study data: `../2026-07-11_load_holding_study/`, `../2026-07-13_per_load_tuning/`,
  `../2026-07-13_smoothness_0.15.4.2/`.
- Plan doc §17–§22 tell the full story chronologically (§22 ends with this reversal).

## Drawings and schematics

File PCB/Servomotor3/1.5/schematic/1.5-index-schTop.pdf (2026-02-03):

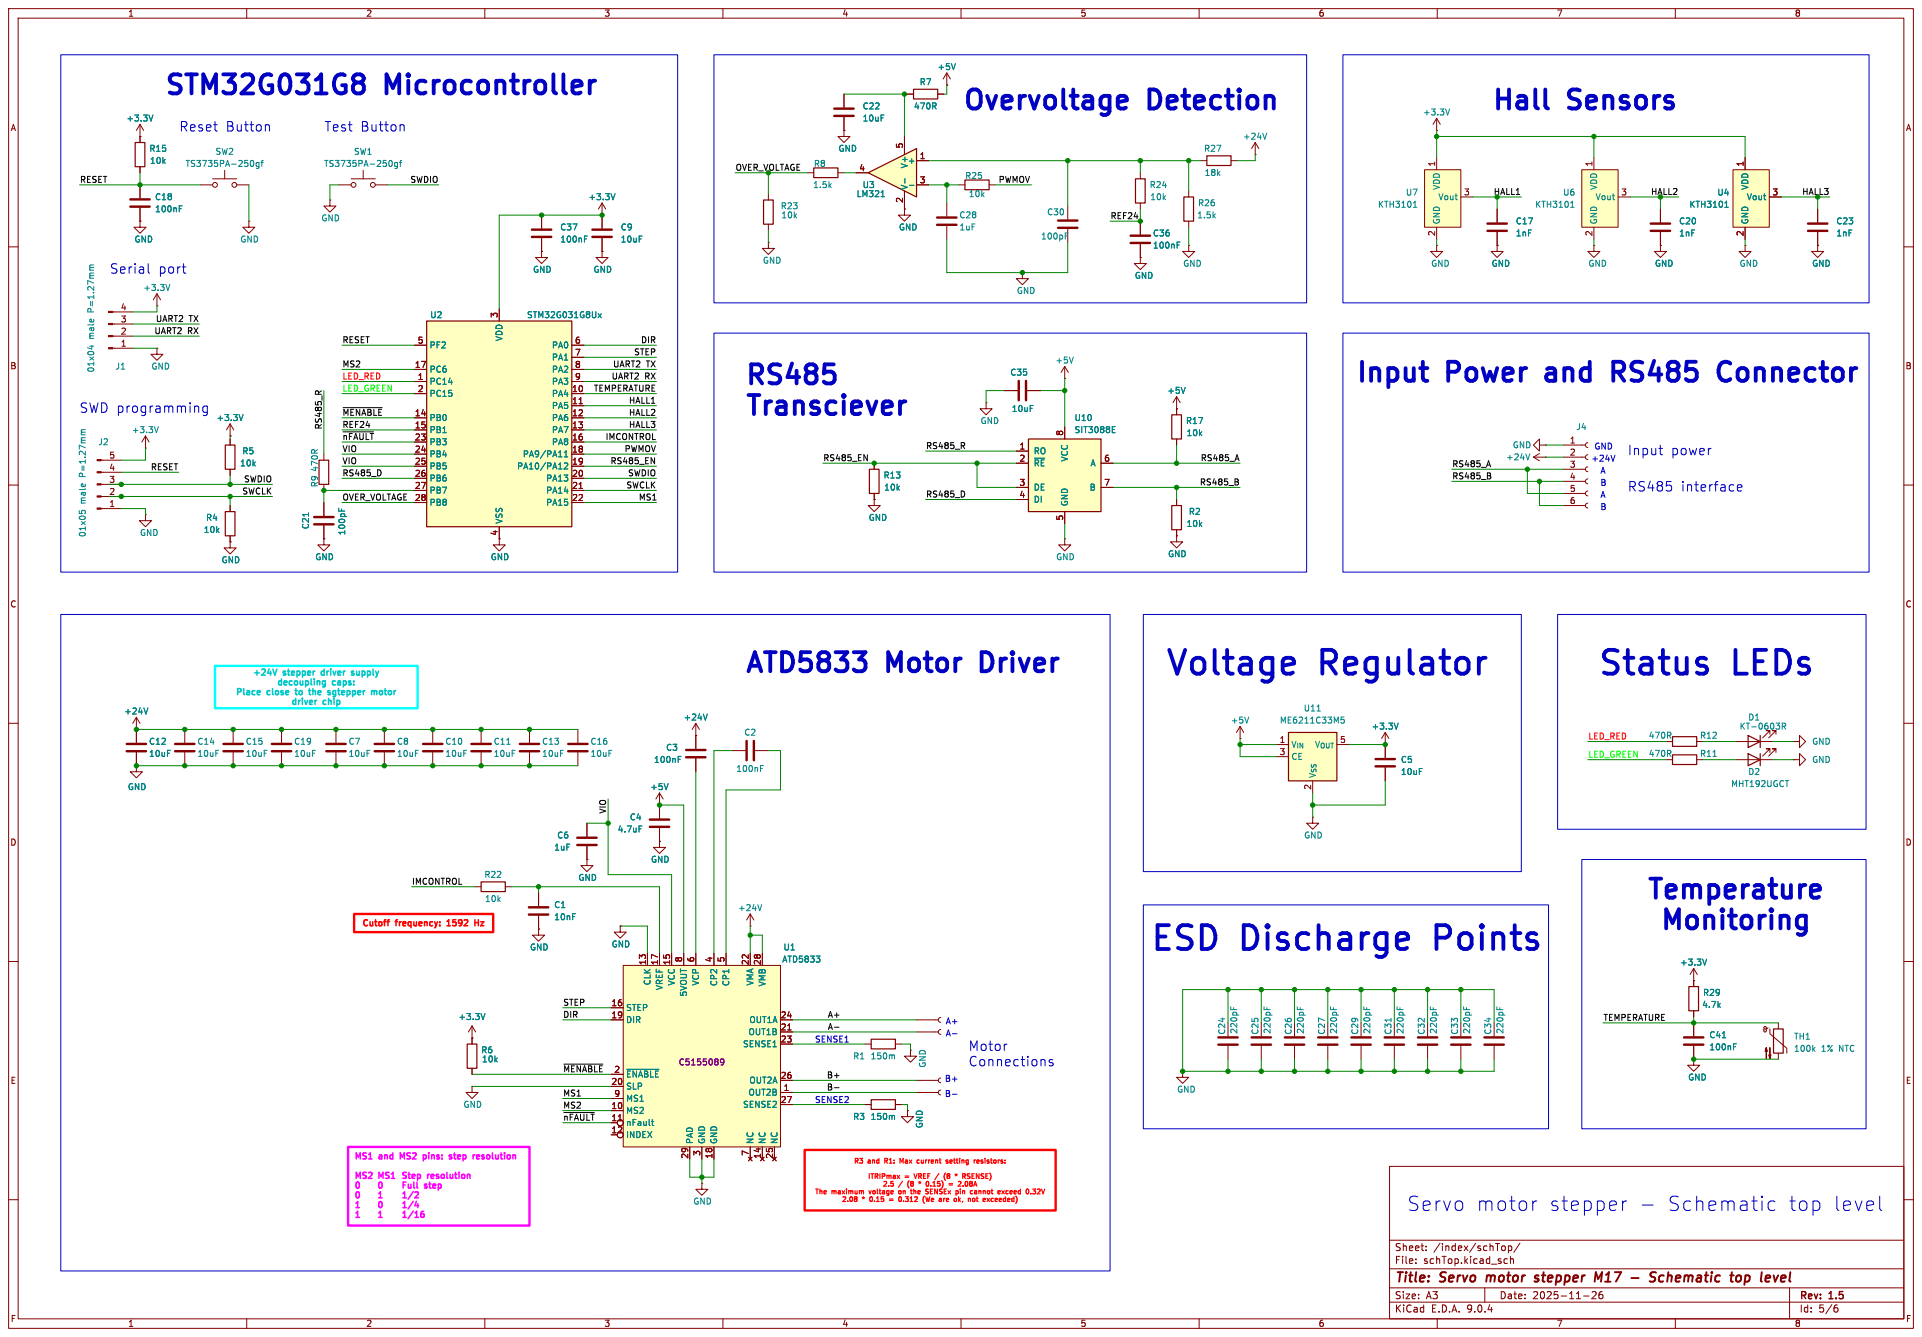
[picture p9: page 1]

3 VSS
IMCONTROL MS1 STEP HALL1 HALL3 HALL2 PWMOV DIR

Input Power and RS485 Connector

7 VMB 28 NC 14 NC 25 OUT1A 24 OUT1B 21 SENSE1 23 OUT2A 26 OUT2B 1 SENSE2 27U1 ATD5833 C5155089 +24V GND

The maximum voltage on the SENSEx pin cannot exceed 0.32V

Id: 5/6 Title: Servo motor stepper M17 - Schematic top level File: schTop.kicad_sch Sheet: /index/schTop/

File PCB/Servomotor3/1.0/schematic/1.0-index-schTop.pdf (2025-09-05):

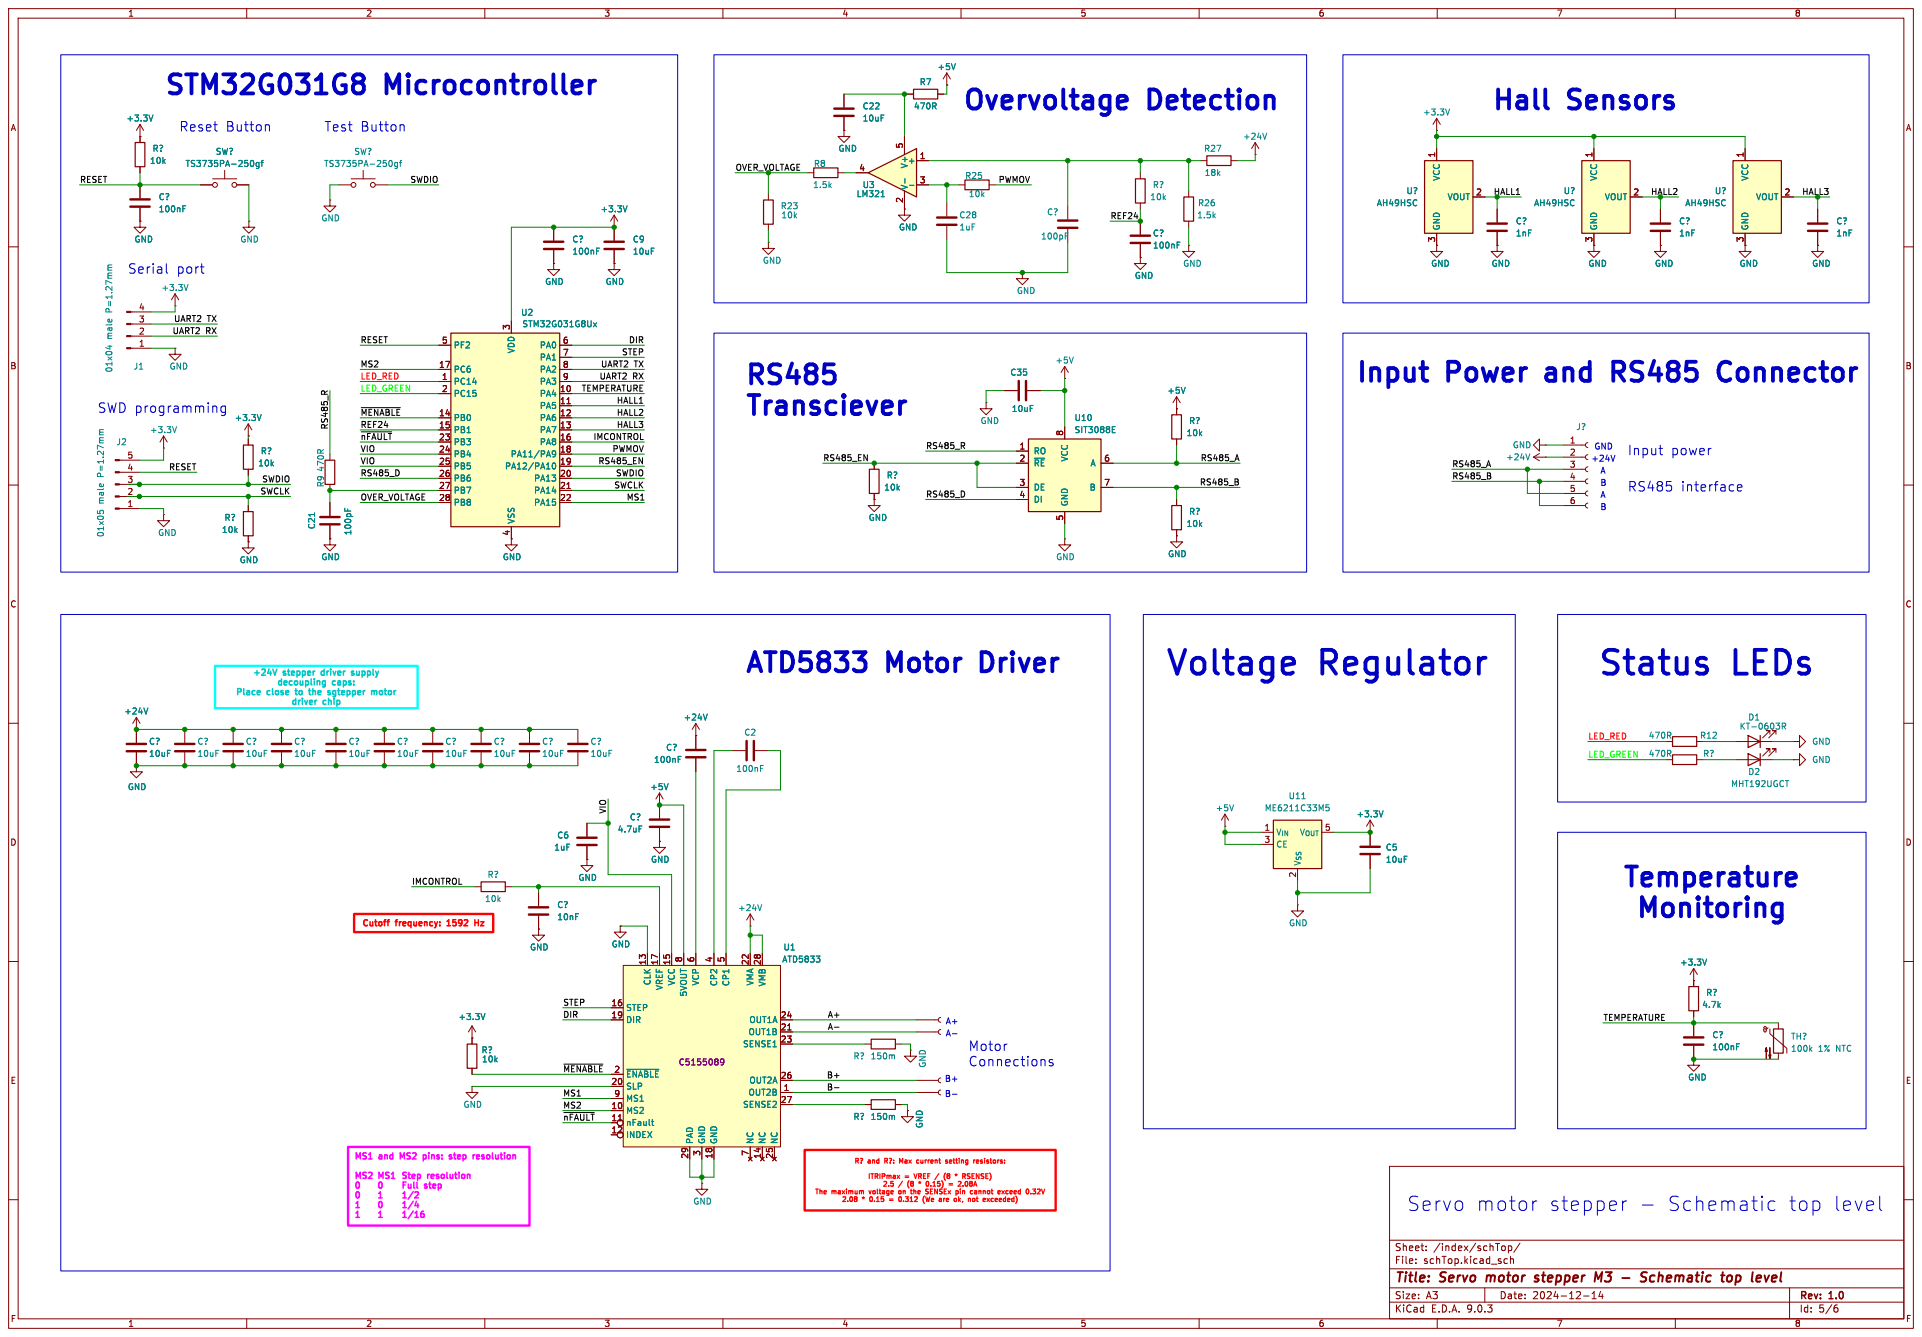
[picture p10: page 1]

7 VMB 28 NC 14 NC 25 OUT1A 24 OUT1B 21 SENSE1 23 OUT2A 26 OUT2B 1 SENSE2 27U1 ATD5833 C5155089 GND

R? and R?: Max current setting resistors:

The maximum voltage on the SENSEx pin cannot exceed 0.32V

Servo motor stepper - Schematic top level

Id: 5/6 Title: Servo motor stepper M3 - Schematic top level File: schTop.kicad_sch Sheet: /index/schTop/

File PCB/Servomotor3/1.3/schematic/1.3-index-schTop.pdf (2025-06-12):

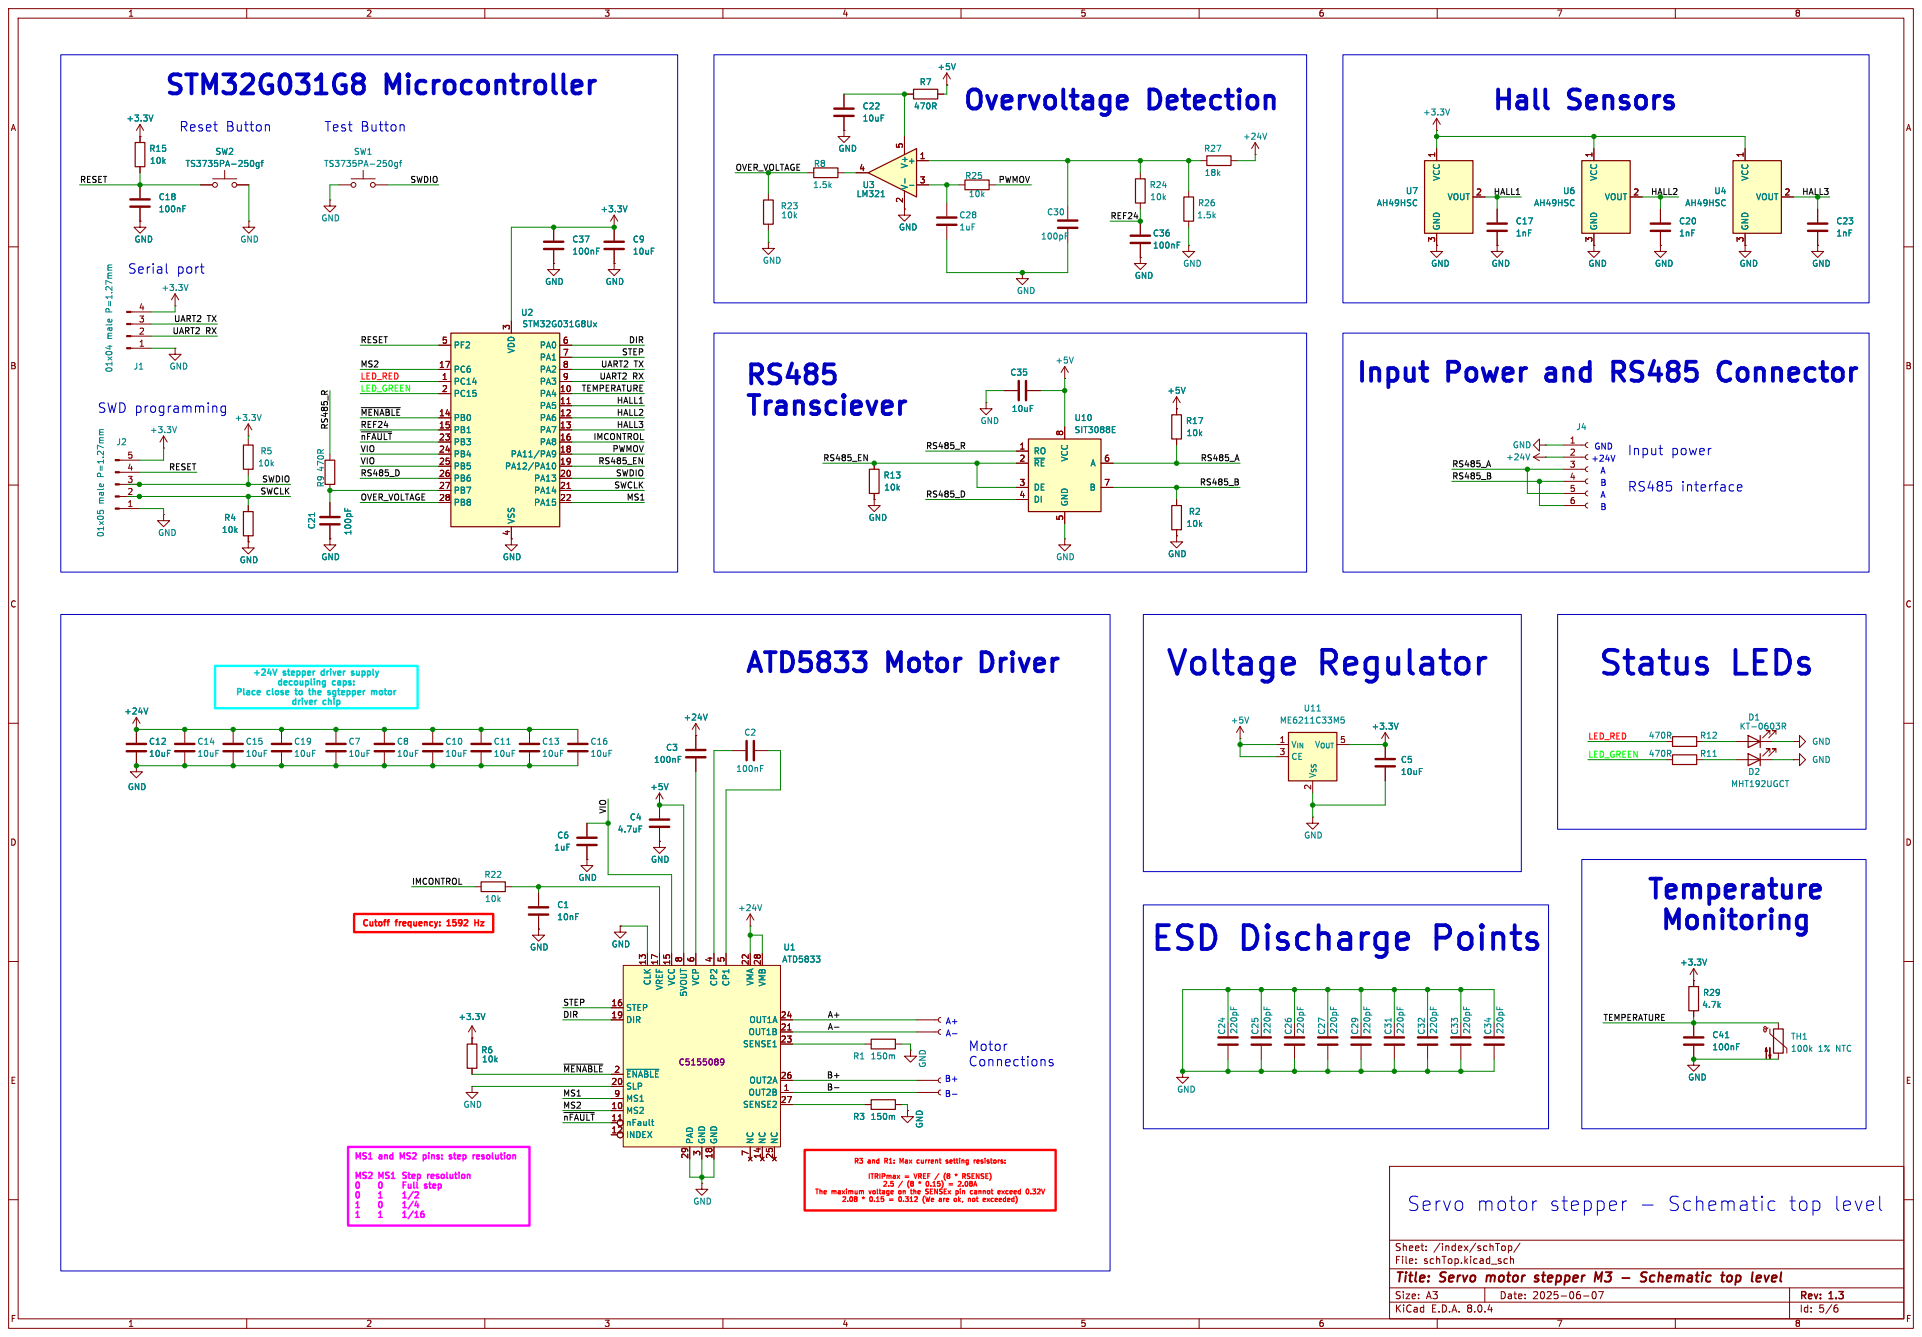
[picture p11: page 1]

Input power GND ESD Discharge Points

Input Power and RS485 Connector

The maximum voltage on the SENSEx pin cannot exceed 0.32V

Servo motor stepper - Schematic top level

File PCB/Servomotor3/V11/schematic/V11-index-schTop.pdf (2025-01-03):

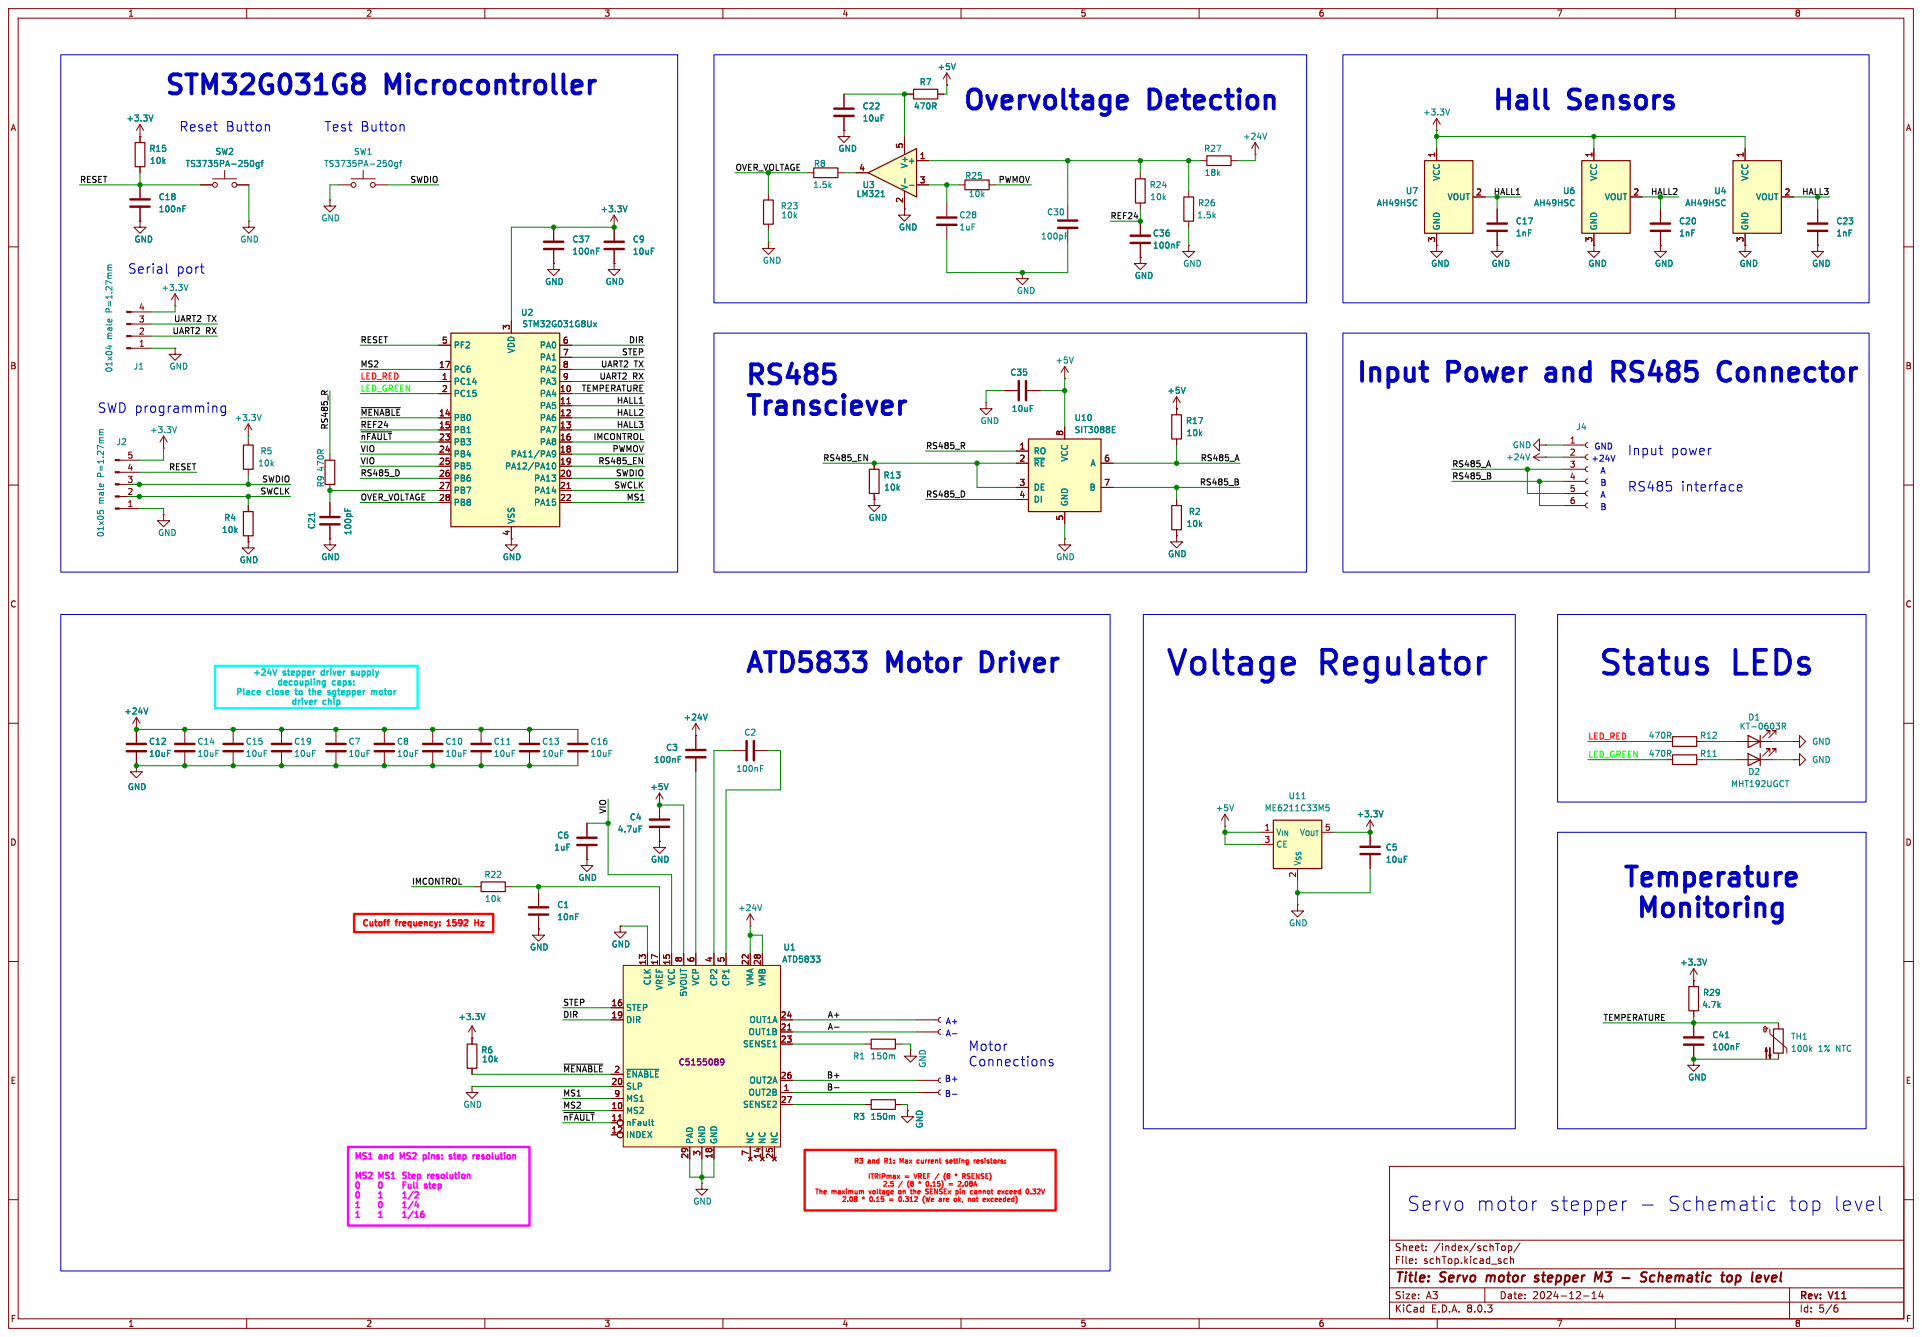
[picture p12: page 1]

+24V Servo motor stepper - Schematic top level A+A- B- RS485
Transciever

Input power AGND Input Power and RS485 Connector

The maximum voltage on the SENSEx pin cannot exceed 0.32V

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

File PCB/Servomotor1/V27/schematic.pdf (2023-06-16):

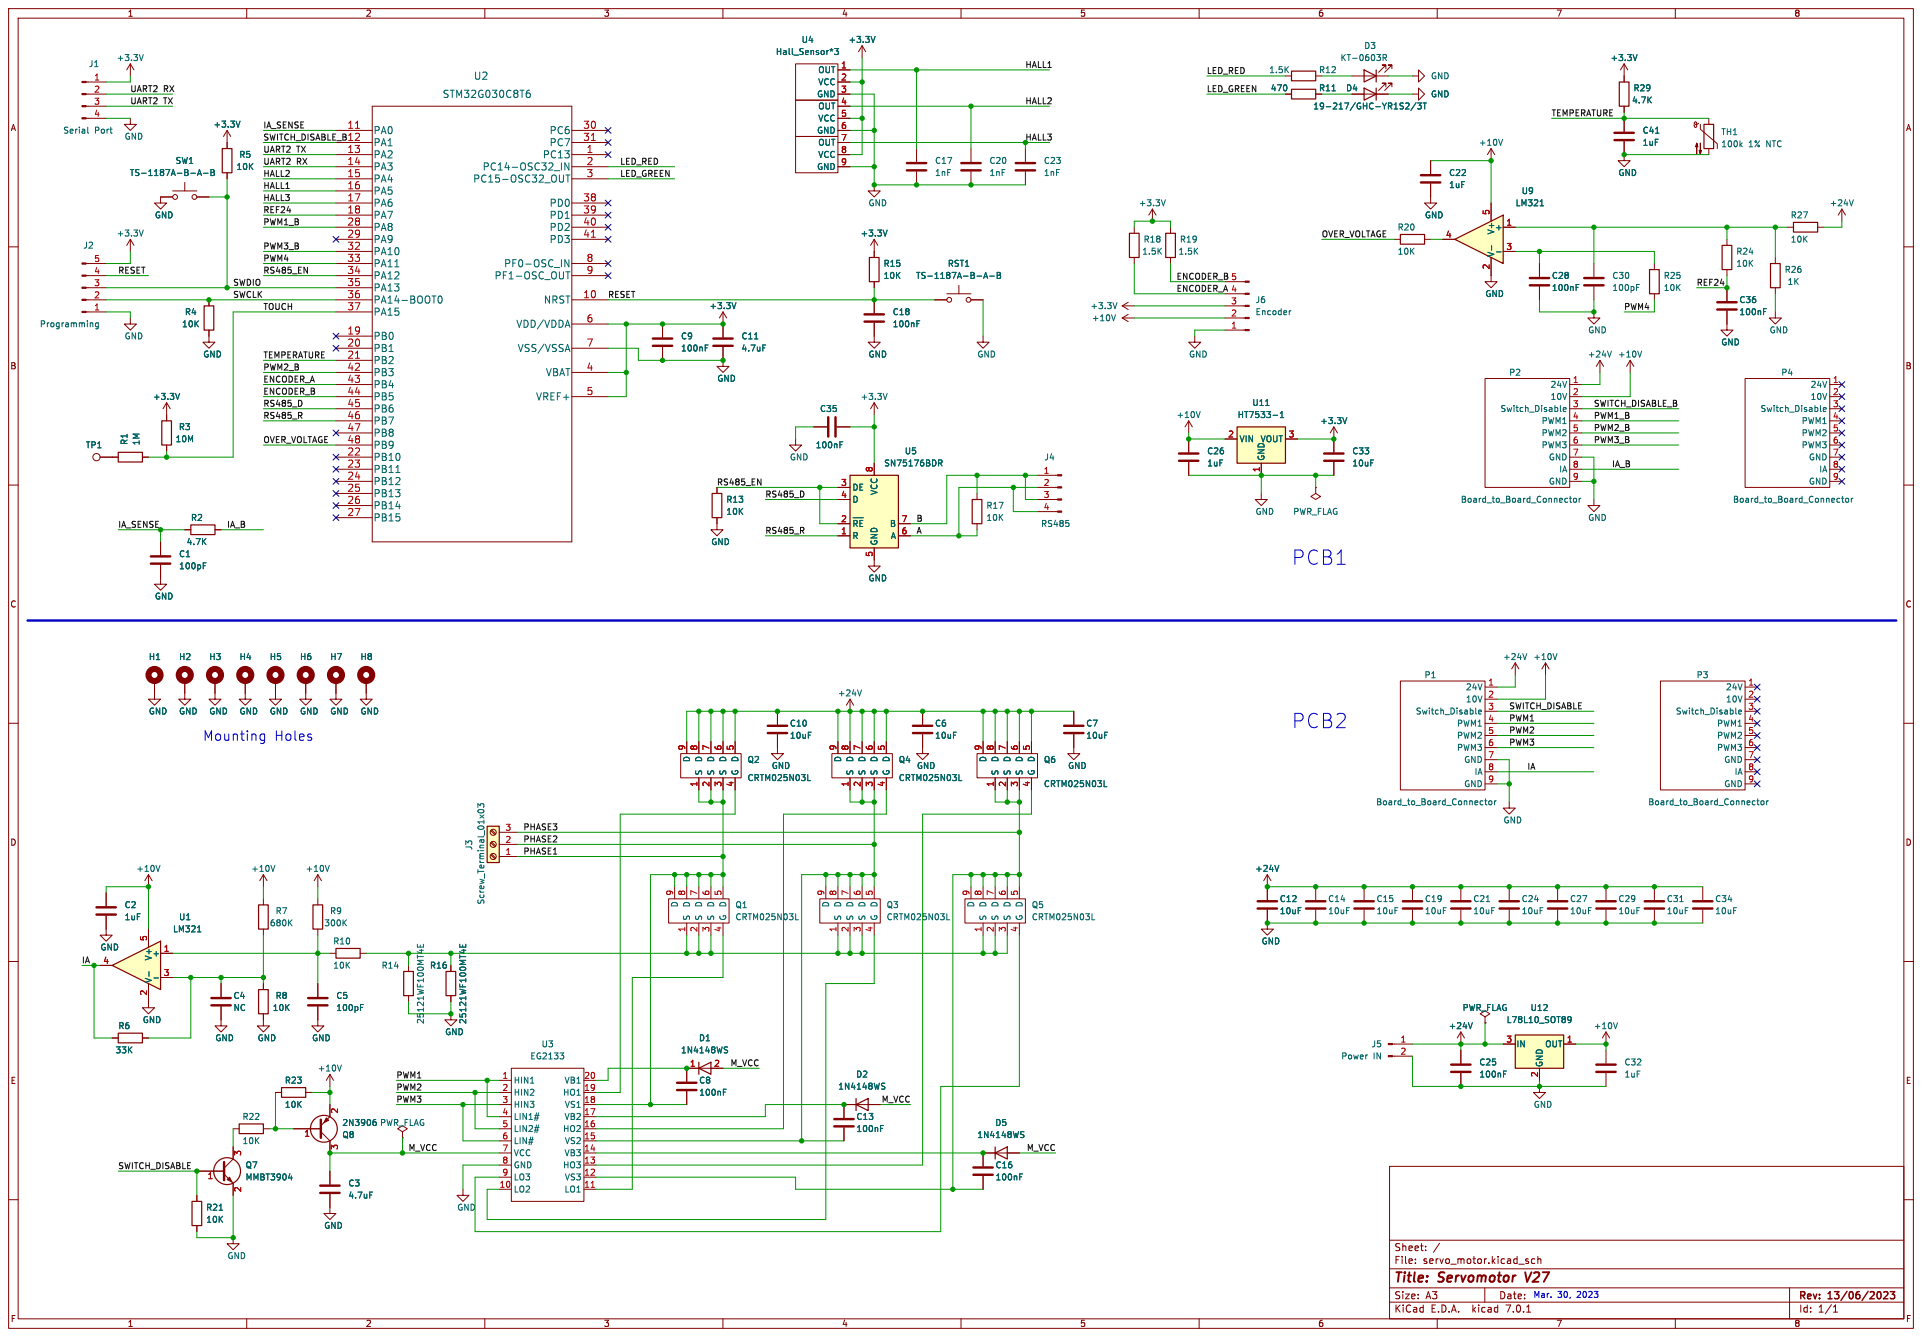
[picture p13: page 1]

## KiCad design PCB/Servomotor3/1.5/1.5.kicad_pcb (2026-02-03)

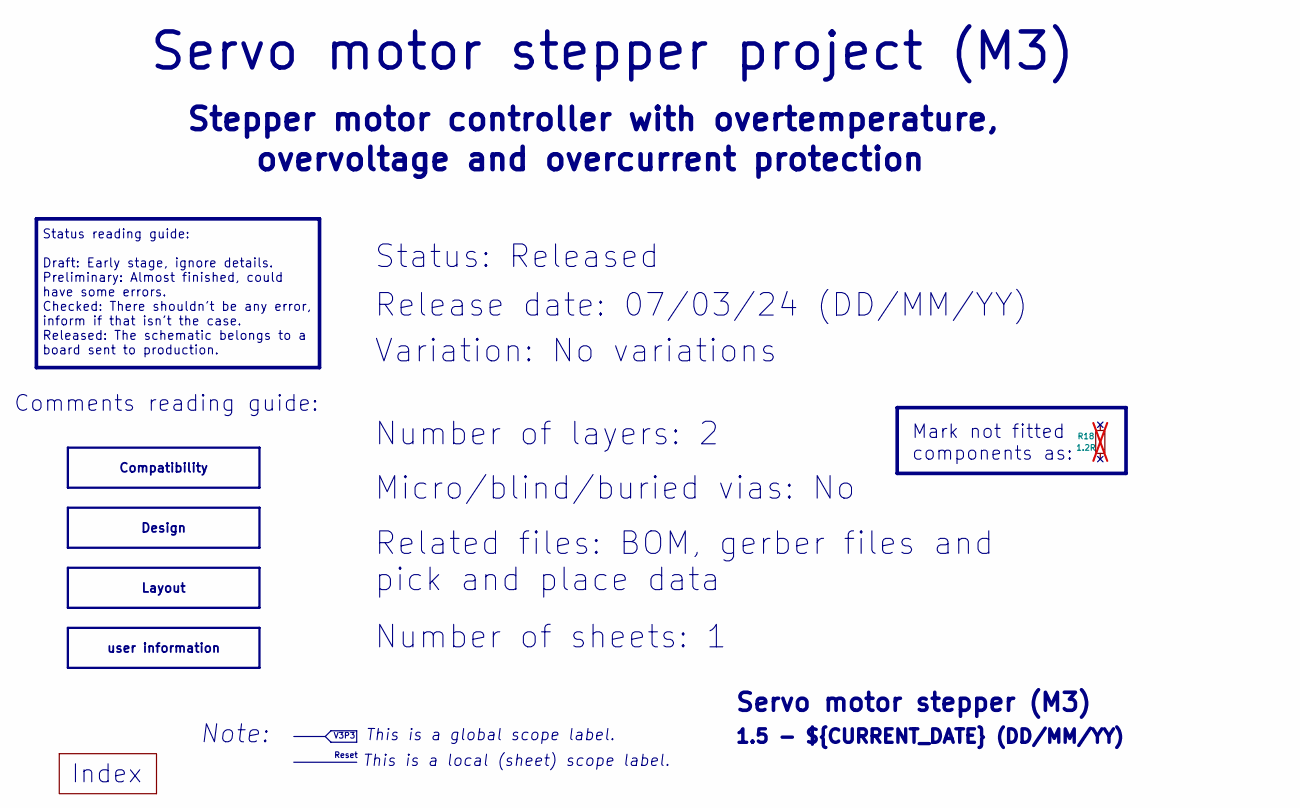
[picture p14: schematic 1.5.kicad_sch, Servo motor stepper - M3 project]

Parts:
R18: 1.2R; R_0402_1005Metric; not fitted

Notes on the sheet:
Variation: No variations
${REVISION} - ${CURRENT_DATE} (DD/MM/YY)
Status reading guide: Draft: Early stage, ignore details. Preliminary: Almost finished, could have some errors. Checked: There shouldn't be any error, inform if that isn't the case. Released: The schematic belongs to a board sent to production.
Servo motor stepper project (M3)
This is a global scope label.
Micro/blind/buried vias: No
Status: Released
Comments reading guide:
overvoltage and overcurrent protection
Reset
Note:
Stepper motor controller with overtemperature,
Related files: BOM, gerber files and pick and place data
Number of sheets: 1
This is a local (sheet) scope label.
Index
Mark not fitted components as:
Number of layers: 2
Release date: 07/03/24 (DD/MM/YY)
V3P3
Servo motor stepper (M3)
Design
user information
Compatibility
Layout

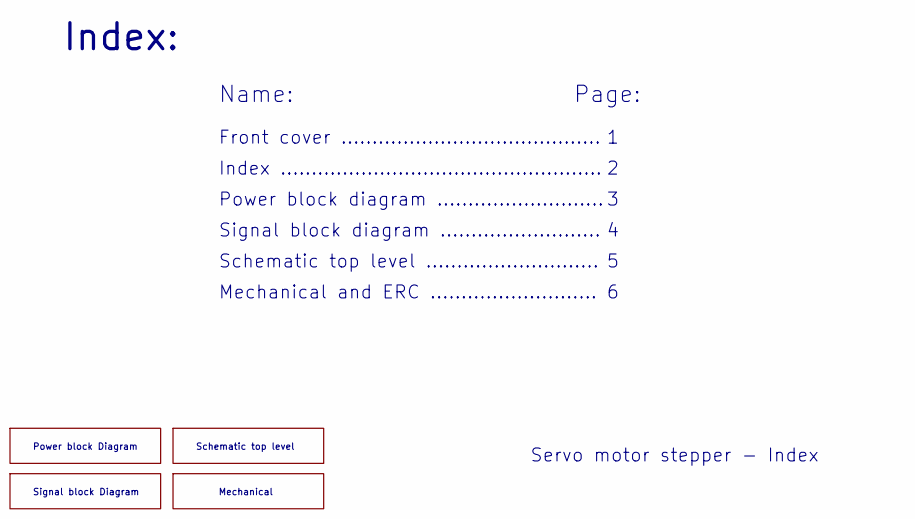
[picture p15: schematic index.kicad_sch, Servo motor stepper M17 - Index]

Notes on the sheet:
Power block Diagram
Front cover ..........................................
Mechanical
Schematic top level
Schematic top level ............................
Index ....................................................
Signal block diagram ..........................
Signal block Diagram
Name:
Mechanical and ERC ...........................
Page:
Servo motor stepper - Index
Power block diagram ...........................
Index:

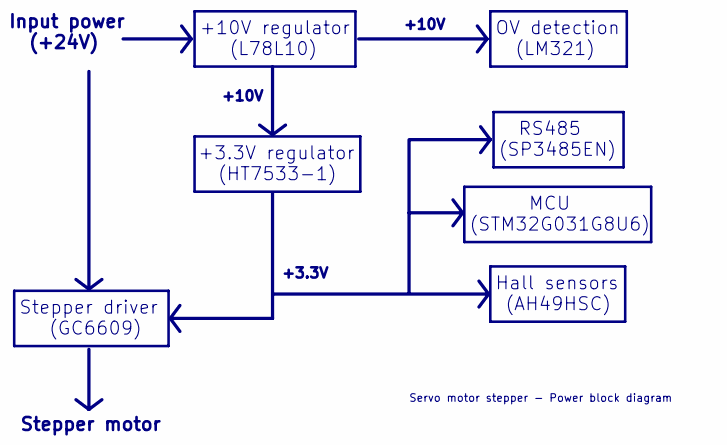
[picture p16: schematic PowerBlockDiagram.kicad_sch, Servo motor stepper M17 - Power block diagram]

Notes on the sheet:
+3.3V
Stepper driver (GC6609)
+10V
RS485 (SP3485EN)
Hall sensors (AH49HSC)
Servo motor stepper - Power block diagram
+3.3V regulator (HT7533-1)
+10V regulator (L78L10)
OV detection (LM321)
Input power (+24V)
Stepper motor
MCU (STM32G031G8U6)

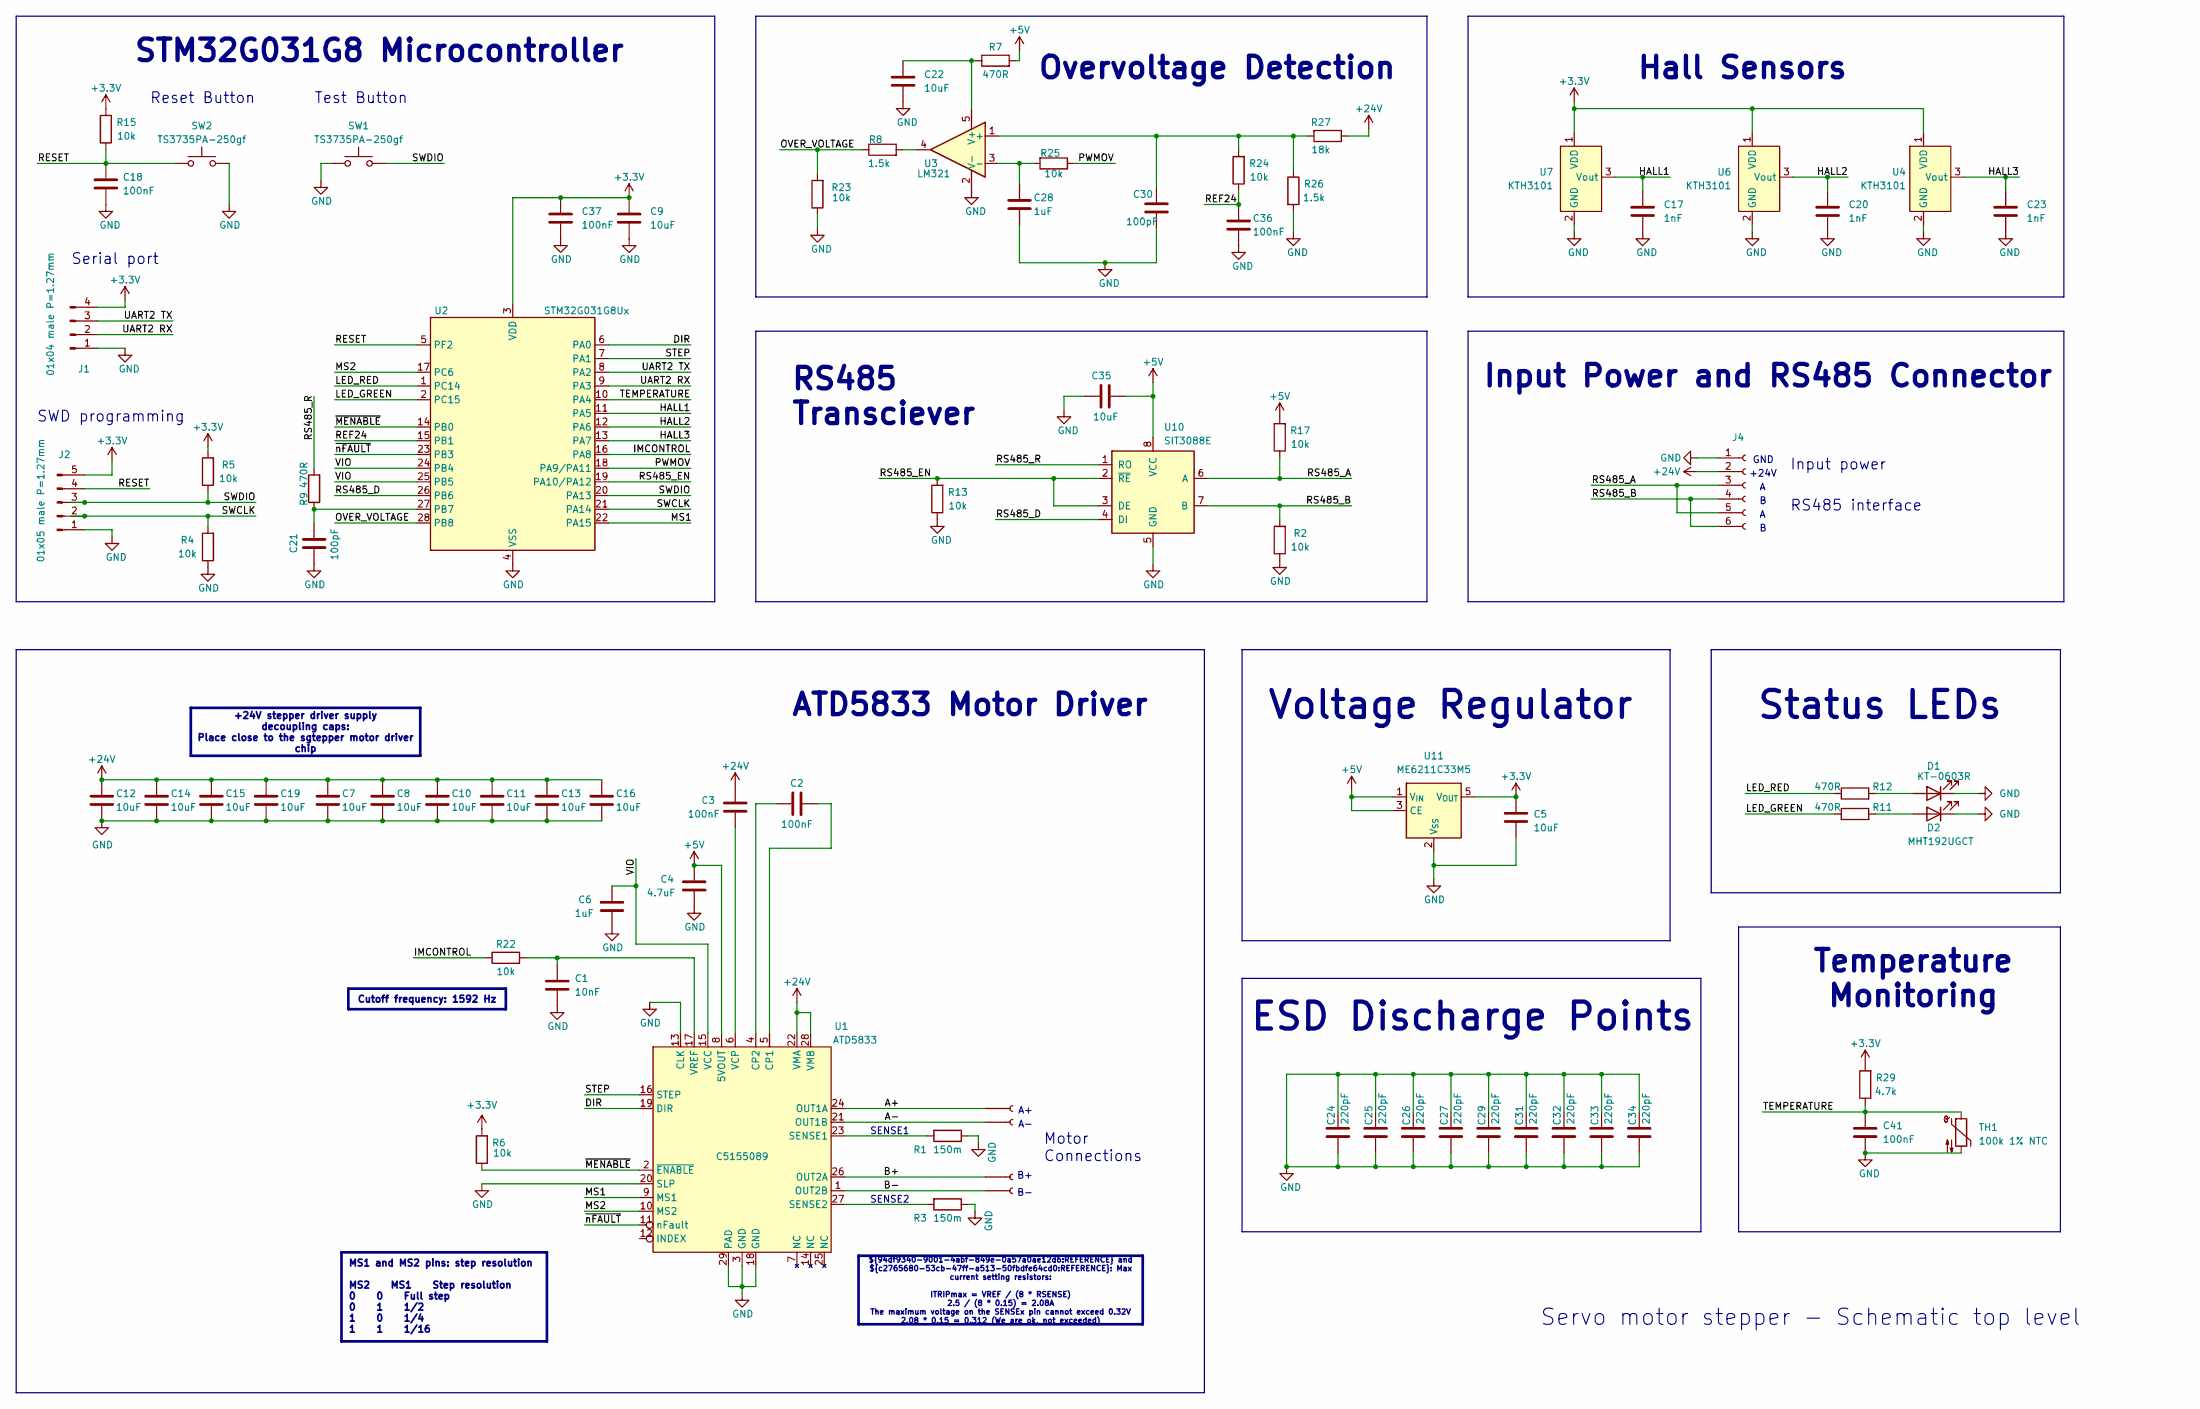
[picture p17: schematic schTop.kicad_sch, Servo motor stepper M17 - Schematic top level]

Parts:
C1: 10nF; C_0402_1005Metric; LCSC C15195
C2, C3, C18, C36, C37, C41: 100nF; C_0402_1005Metric; LCSC C307331
C4: 4.7uF; C_0402_1005Metric; LCSC C23733
C5, C9, C22, C35: 10uF; C_0402_1005Metric; LCSC C15525
C6, C28: 1uF; C_0402_1005Metric; LCSC C52923
C7, C8, C10, C11, C12, C13, C14, C15, C16, C19: 10uF; C_0603_1608Metric; LCSC C194427
C17, C20, C23: 1nF; C_0402_1005Metric; LCSC C1523
C21, C30: 100pF; C_0402_1005Metric; LCSC C1546
C24, C25, C26, C27, C29, C31, C32, C33, C34: 220pF; C_0402_1005Metric; LCSC C1530
D1: KT-0603R; LED_0603_1608Metric; LCSC C2286
D2: MHT192UGCT; LED_0603_1608Metric; LCSC C389519
J1: 01x04 male P=1.27mm; PinHeader_1x04_P1.27mm_Vertical_No_Silkprint
J2: 01x05 male P=1.27mm; PinHeader_1x05_P1.27mm_Vertical_No_Silkprint
J3, J5, J6, J7: Conn_01x01_Socket; Pad_3mm_TopOnly
J4: Conn_01x06_Socket; PinSocket_1x06_P2.00mm_Vertical
R1, R3: 150m; R_2010_5025Metric; LCSC C474275
R2, R4, R5, R6, R13, R15, R17, R22, R23, R24, R25: 10k; R_0402_1005Metric; LCSC C25744
R7, R9, R11, R12: 470R; R_0402_1005Metric; LCSC C25117
R8, R26: 1.5k; R_0402_1005Metric; LCSC C25867
R27: 18k; R_0603_1608Metric; LCSC C25810
R29: 4.7k; R_0402_1005Metric; LCSC C25900
SW1, SW2: TS3735PA-250gf; LCSC C393946
TH1: 100k 1% NTC; R_0402_1005Metric; LCSC C236279
U1: ATD5833; QFN-28-1EP_5x5mm_P0.5mm_EP3.75x3.75mm_ThermalVias; LCSC C5155089
U2: STM32G031G8Ux; QFN-28_4x4mm_P0.5mm; LCSC C432211
U3: LM321; SOT-23-5; LCSC C19723728
U4, U6, U7: KTH3101; DFN1616; LCSC C49258056
U10: SIT3088E; DFN-8-1EP_3x3mm_P0.65mm_EP1.5x2.25mm; LCSC C601076
U11: ME6211C33M5; SOT-23-5; LCSC C82942

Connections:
+3.3V: C5.1, C9.1, C37.1, J1.4, J2.5, R5.2, R6.2, R15.2, R29.2, U2.3 (VDD), U4.1 (VDD), U6.1 (VDD), U7.1 (VDD), U11.5 (V_{OUT})
+5V: C4.1, C35.2, R7.2, R17.2, U1.8 (5VOUT), U10.8 (VCC), U11.1 (V_{IN}), U11.3 (CE)
+24V: C3.1, C7.1, C8.1, C10.1, C11.1, C12.1, C13.1, C14.1, C15.1, C16.1, C19.1, J4.2, R27.1, U1.22 (VMA), U1.28 (VMB)
/index/schTop/A+: J3.1, U1.24 (OUT1A)
/index/schTop/A-: J6.1, U1.21 (OUT1B)
/index/schTop/B+: J7.1, U1.26 (OUT2A)
/index/schTop/B-: J5.1, U1.1 (OUT2B)
/index/schTop/DIR: U1.19 (DIR), U2.6 (PA0)
/index/schTop/HALL1: C17.1, U2.11 (PA5), U7.3 (Vout)
/index/schTop/HALL2: C20.1, U2.12 (PA6), U6.3 (Vout)
/index/schTop/HALL3: C23.1, U2.13 (PA7), U4.3 (Vout)
/index/schTop/IMCONTROL: R22.1, U2.16 (PA8)
/index/schTop/LED_GREEN: R11.1, U2.2 (PC15)
/index/schTop/LED_RED: R12.1, U2.1 (PC14)
/index/schTop/MS1: U1.9 (MS1), U2.22 (PA15)
/index/schTop/MS2: U1.10 (MS2), U2.17 (PC6)
/index/schTop/OVER_VOLTAGE: R8.1, R23.2, U2.28 (PB8)
/index/schTop/PWMOV: R25.1, U2.18 (PA9/PA11)
/index/schTop/REF24: C36.1, R24.1, U2.15 (PB1)
/index/schTop/RESET: C18.1, J2.4, R15.1, SW2.1, U2.5 (PF2)
/index/schTop/RS485_A: J4.3, J4.5, R17.1, U10.6 (A)
/index/schTop/RS485_B: J4.4, J4.6, R2.2, U10.7 (B)
/index/schTop/RS485_D: U2.26 (PB6), U10.4 (DI)
/index/schTop/RS485_EN: R13.2, U2.19 (PA10/PA12), U10.2 (~RE), U10.3 (DE)
/index/schTop/RS485_R: R9.2, U10.1 (RO)
/index/schTop/STEP: U1.16 (STEP), U2.7 (PA1)
/index/schTop/SWCLK: J2.2, R4.2, U2.21 (PA14)
/index/schTop/SWDIO: J2.3, R5.1, SW1.2, U2.20 (PA13)
/index/schTop/TEMPERATURE: C41.1, R29.1, TH1.1, U2.10 (PA4)
/index/schTop/UART2 RX: J1.2, U2.9 (PA3)
/index/schTop/UART2 TX: J1.3, U2.8 (PA2)
/index/schTop/VIO: C6.1, U1.15 (VCC), U2.24 (PB4), U2.25 (PB5)
/index/schTop/~MENABLE: R6.1, U1.2 (~ENABLE), U2.14 (PB0)
/index/schTop/~nFAULT: U1.11 (nFault), U2.23 (PB3)
GND: C1.2, C4.2, C5.2, C6.2, C7.2, C8.2, C9.2, C10.2, C11.2, C12.2, C13.2, C14.2, C15.2, C16.2, C17.2, C18.2, C19.2, C20.2, C21.2, C22.2, C23.2, C24.1, C24.2, C25.1, C25.2, C26.1, C26.2, C27.1, C27.2, C28.2, C29.1, C29.2, C30.2, C31.1, C31.2, C32.1, C32.2, C33.1, C33.2, C34.1, C34.2, C35.1, C36.2, C37.2, C41.2, D1.1 (K), D2.1 (K), J1.1, J2.1, J4.1, R1.1, R2.1, R3.1, R4.1, R13.1, R23.1, R26.2, SW1.1, SW2.2, TH1.2, U1.3 (GND), U1.13 (CLK), U1.18 (GND), U1.20 (SLP), U1.29 (PAD), U2.4 (VSS), U3.2 (V-), U4.2 (GND), U6.2 (GND), U7.2 (GND), U10.5 (GND), U11.2 (V_{SS})
unnamed: D1.2 (A), R12.2
unnamed: D2.2 (A), R11.2
unnamed: R8.2, U3.4
unnamed: C2.2, U1.5 (CP1)
unnamed: C2.1, U1.4 (CP2)
unnamed: R1.2, U1.23 (SENSE1)
unnamed: R3.2, U1.27 (SENSE2)
unnamed: C3.2, U1.6 (VCP)
unnamed: C1.1, R22.2, U1.17 (VREF)
unnamed: C21.1, R9.1, U2.27 (PB7)
unnamed: C30.1, R24.2, R26.1, R27.2, U3.1 (+)
unnamed: C28.1, R25.2, U3.3 (-)
unnamed: C22.1, R7.1, U3.5 (V+)

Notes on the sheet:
Reset Button
ESD Discharge Points
Test Button
+24V
SWD programming
Serial port
GND
RS485 Transciever
Input power
Status LEDs
Overvoltage Detection
Voltage Regulator
Input Power and RS485 Connector
SENSE2
RS485 interface
Temperature Monitoring
SENSE1
Servo motor stepper - Schematic top level
STM32G031G8 Microcontroller
ATD5833 Motor Driver
Hall Sensors
Motor Connections
Cutoff frequency: 1592 Hz
+24V stepper driver supply decoupling caps: Place close to the sgtepper motor driver chip
MS1 and MS2 pins: step resolution MS2 MS1 Step resolution 0 0 Full step 0 1 1/2 1 0 1/4 1 1 1/16
${94df9340-9001-4abf-849e-0a57a0ae12d6:REFERENCE} and ${c2765680-53cb-47ff-a513-50fbdfe64cd0:REFERENCE}: Max current setting resistors: ITRIPmax = VREF / (8 * RSENSE) 2.5 / (8 * 0.15) = 2.08A The maximum voltage on the SENSEx pin cannot exceed 0.32V 2.08 * 0.15 = 0.312 (We are ok, not exceeded)

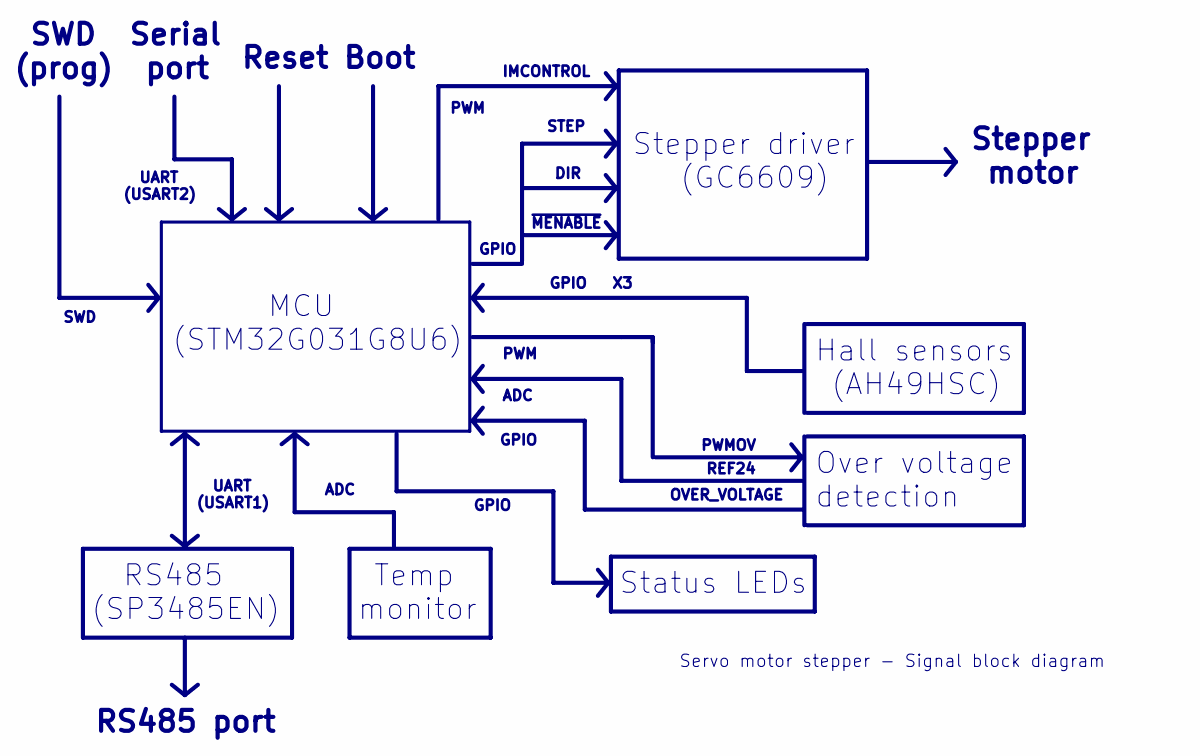
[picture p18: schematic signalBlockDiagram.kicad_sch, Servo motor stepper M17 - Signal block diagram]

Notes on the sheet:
~{MENABLE}
Stepper driver (GC6609)
Serial port
REF24
RS485 (SP3485EN)
Temp monitor
UART (USART2)
MCU (STM32G031G8U6)
IMCONTROL
ADC
UART (USART1)
PWM
GPIO
STEP
SWD (prog)
Over voltage detection
OVER_VOLTAGE
Status LEDs
Boot
PWMOV
Reset
DIR
Stepper motor
RS485 port
Servo motor stepper - Signal block diagram
Hall sensors (AH49HSC)
SWD

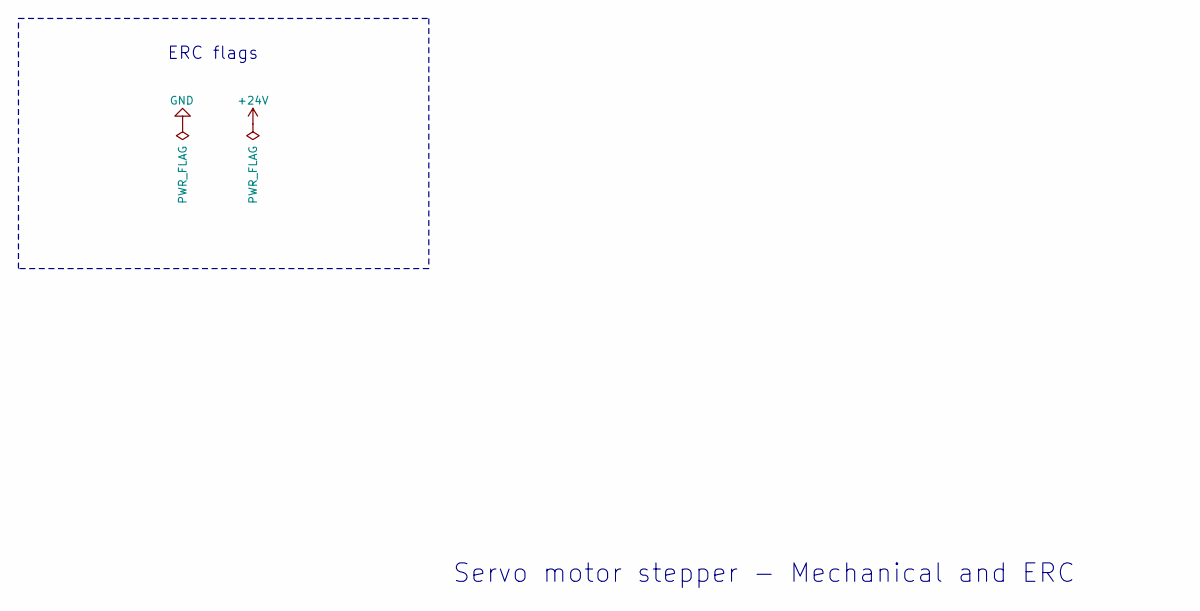
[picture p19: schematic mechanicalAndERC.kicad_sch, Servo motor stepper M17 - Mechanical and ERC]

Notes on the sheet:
ERC flags
Servo motor stepper - Mechanical and ERC

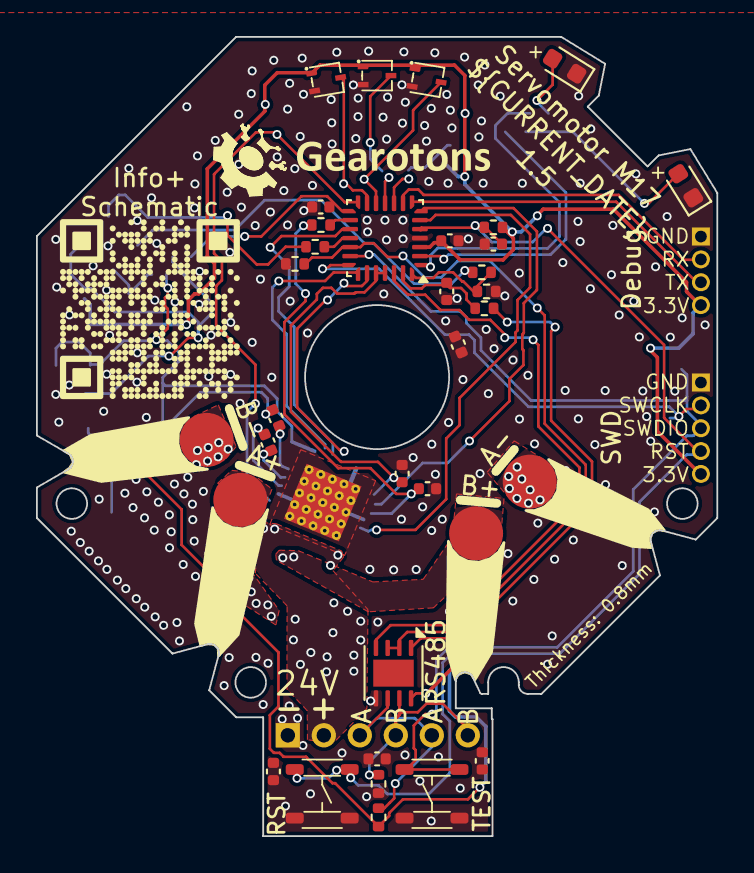
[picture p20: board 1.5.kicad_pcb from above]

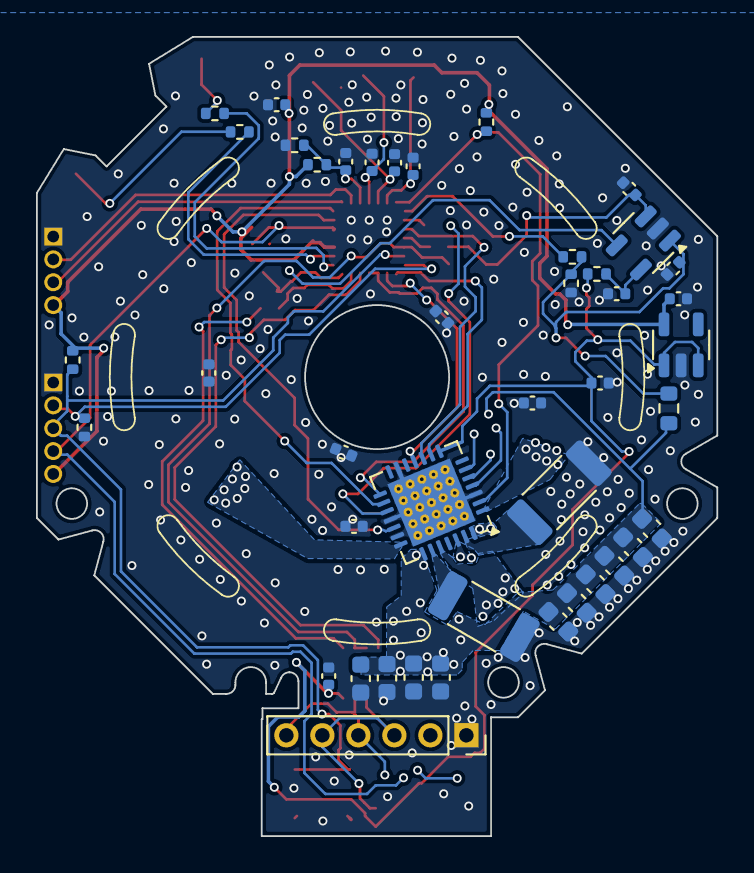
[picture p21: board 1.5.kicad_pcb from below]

Board: 2 copper layers, 37.8 x 44.4 mm, 79 parts (43 on the bottom side), 48 nets.

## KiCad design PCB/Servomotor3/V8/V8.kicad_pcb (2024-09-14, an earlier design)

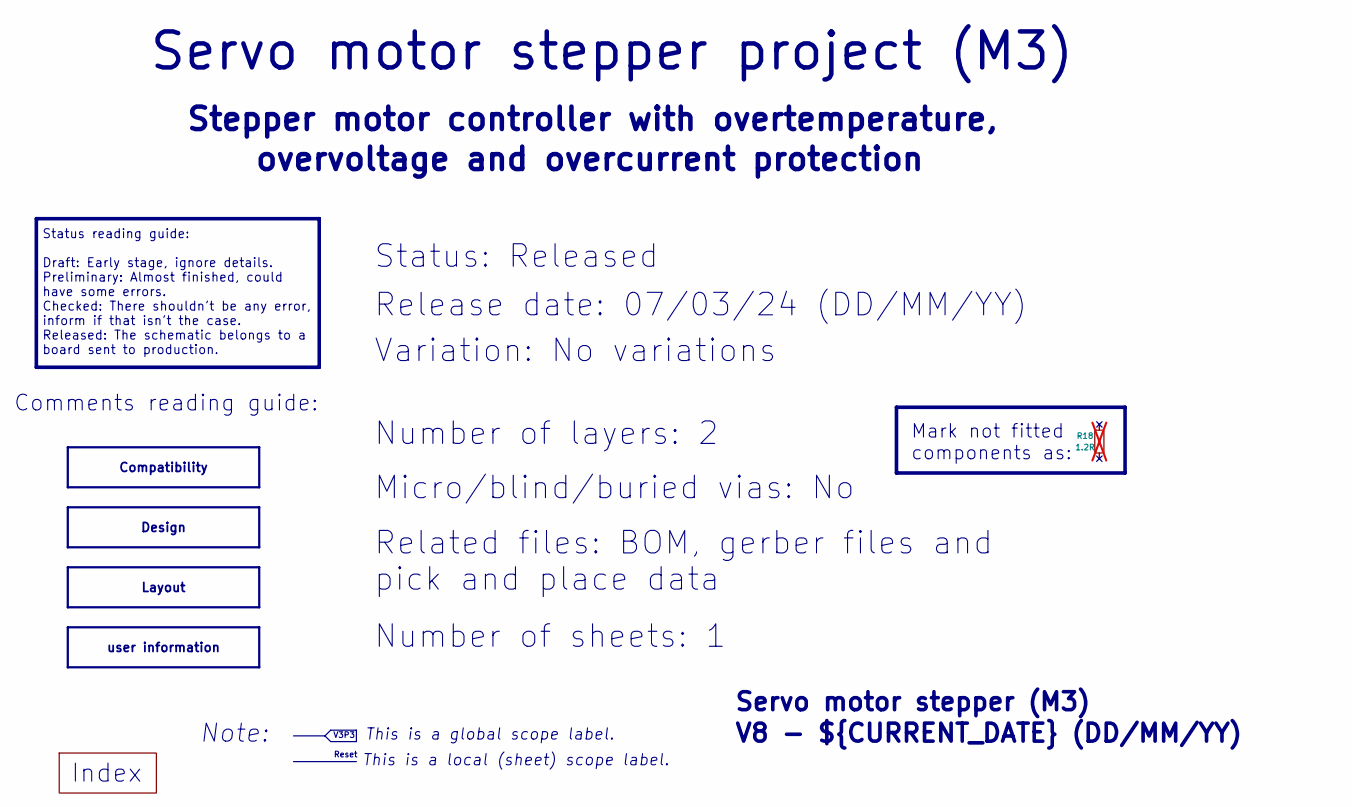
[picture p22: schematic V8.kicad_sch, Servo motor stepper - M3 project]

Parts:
R18: 1.2R; R_0402_1005Metric; not fitted

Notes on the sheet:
Design
user information
Compatibility
Layout
Variation: No variations
${REVISION} - ${CURRENT_DATE} (DD/MM/YY)
Status reading guide: Draft: Early stage, ignore details. Preliminary: Almost finished, could have some errors. Checked: There shouldn't be any error, inform if that isn't the case. Released: The schematic belongs to a board sent to production.
Servo motor stepper project (M3)
This is a global scope label.
Micro/blind/buried vias: No
Status: Released
Comments reading guide:
overvoltage and overcurrent protection
Reset
Note:
Stepper motor controller with overtemperature,
Related files: BOM, gerber files and pick and place data
Number of sheets: 1
This is a local (sheet) scope label.
Index
Mark not fitted components as:
Number of layers: 2
Release date: 07/03/24 (DD/MM/YY)
V3P3
Servo motor stepper (M3)


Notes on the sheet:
Power block Diagram
Front cover ..........................................
Mechanical
Schematic top level
Schematic top level ............................
Index ....................................................
Signal block diagram ..........................
Signal block Diagram
Name:
Mechanical and ERC ...........................
Page:
Servo motor stepper - Index
Power block diagram ...........................
Index:


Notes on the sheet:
+3.3V
Stepper driver (GC6609)
+10V
RS485 (SP3485EN)
Hall sensors (AH49HSC)
Servo motor stepper - Power block diagram
+3.3V regulator (HT7533-1)
+10V regulator (L78L10)
OV detection (LM321)
Input power (+24V)
Stepper motor
MCU (STM32G031G8U6)

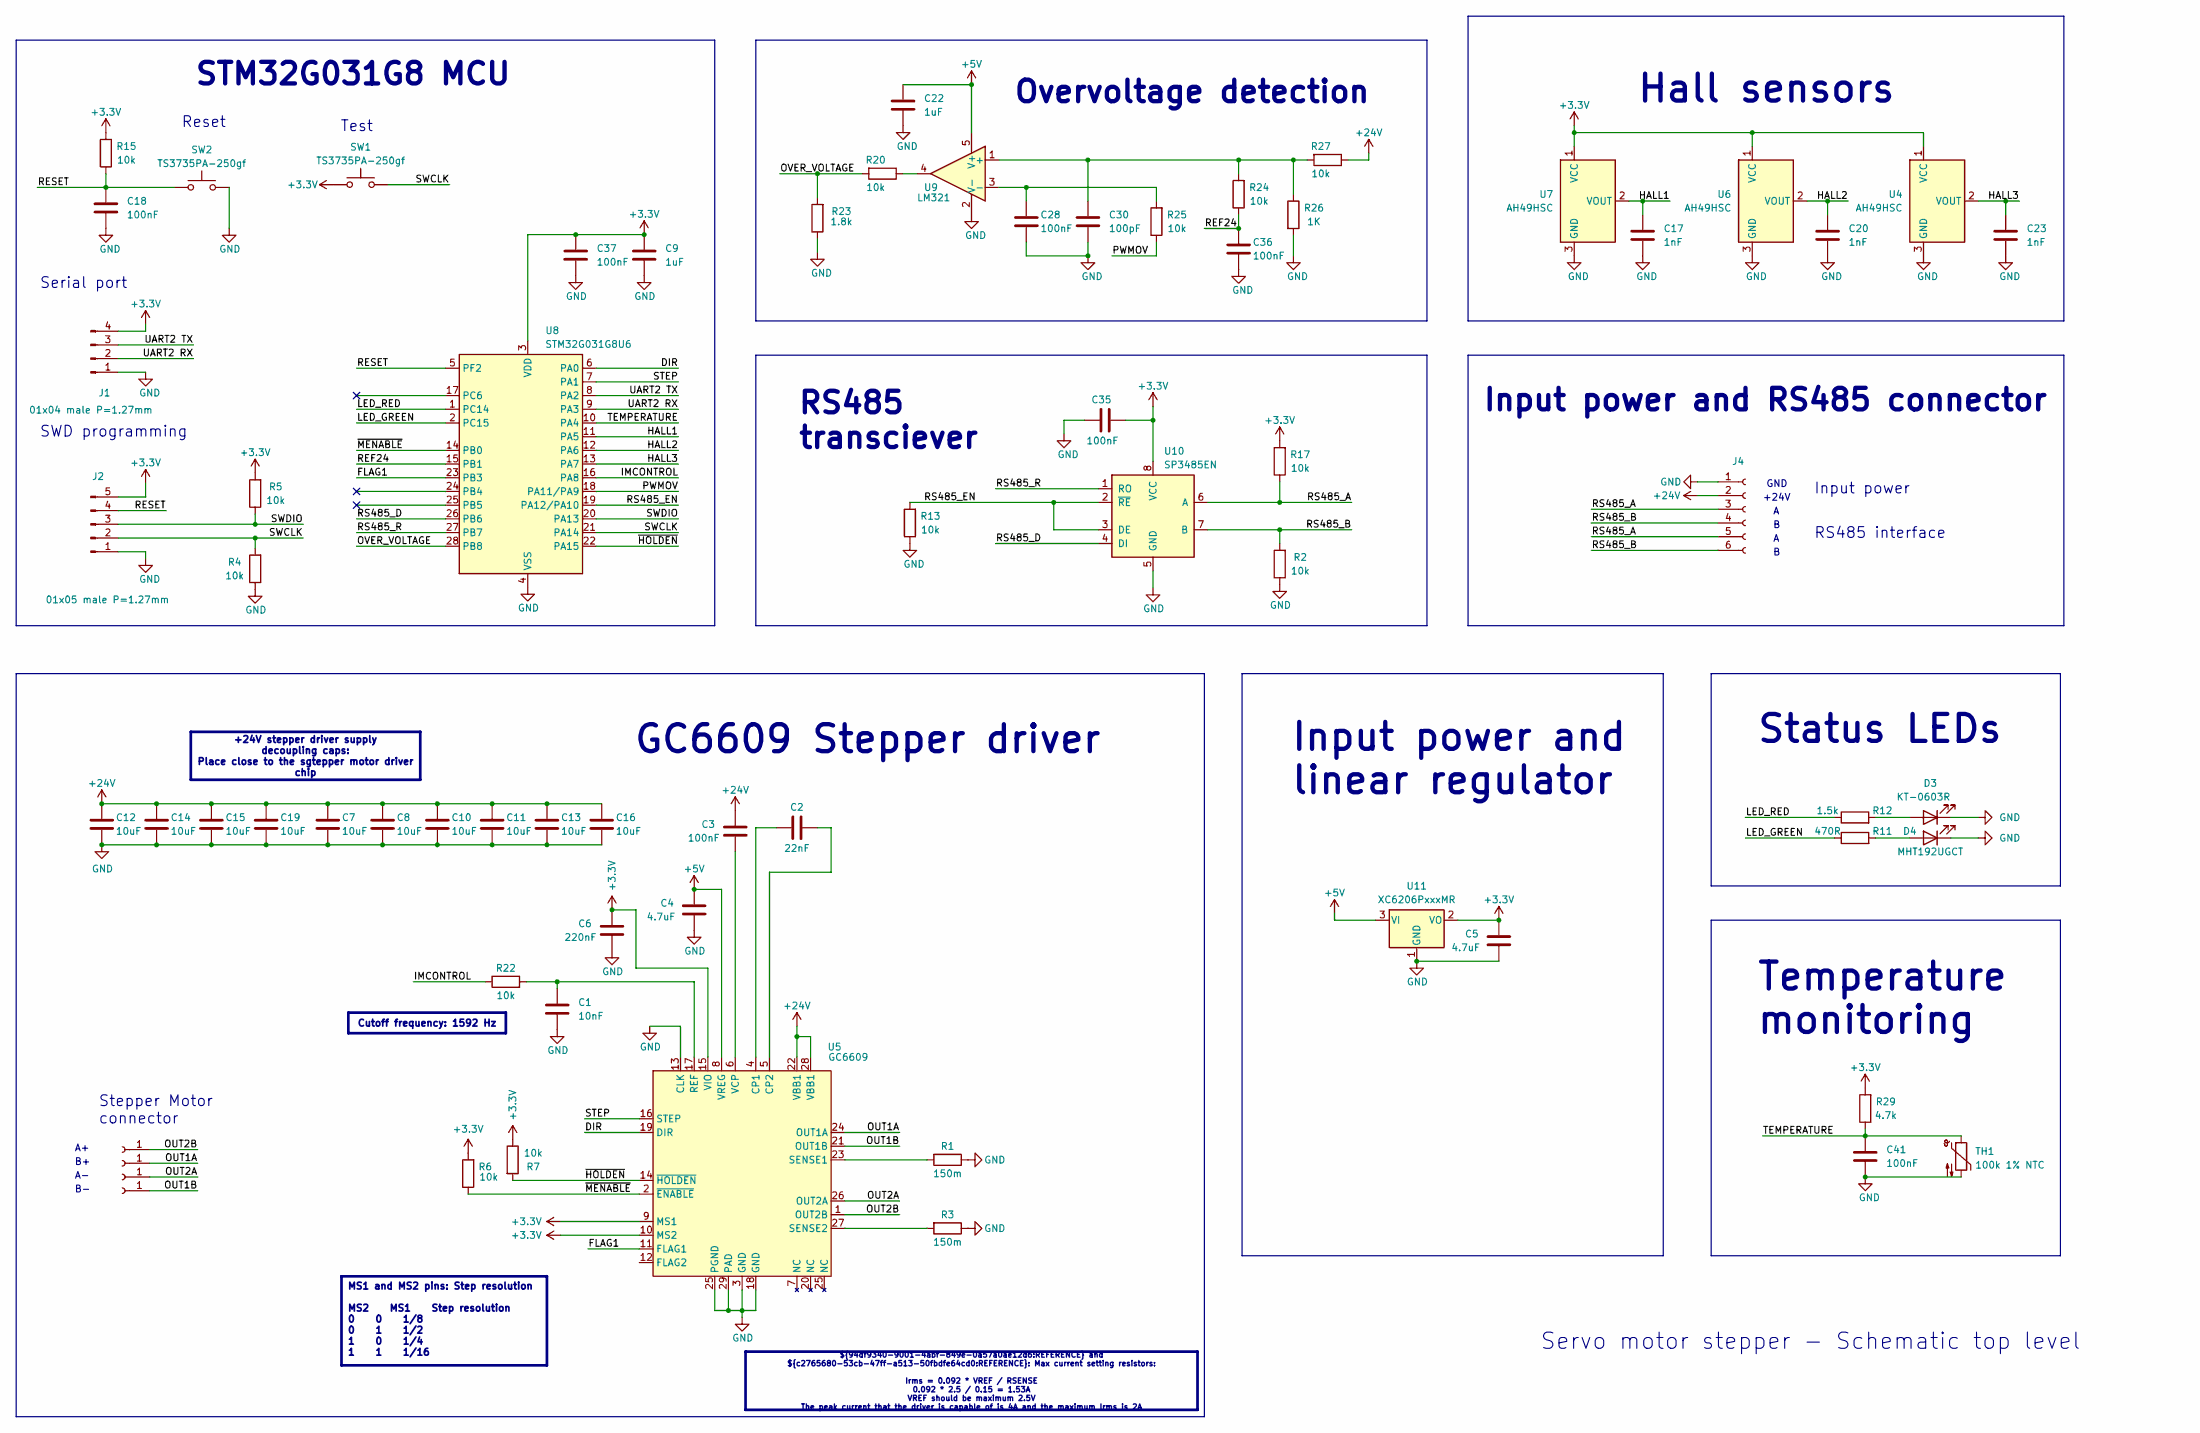
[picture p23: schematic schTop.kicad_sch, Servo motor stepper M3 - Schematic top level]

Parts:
C1: 10nF; C_0402_1005Metric; LCSC C15195
C2: 22nF; C_0402_1005Metric; LCSC C1532
C3, C18, C28, C35, C36, C37, C41: 100nF; C_0402_1005Metric; LCSC C307331
C4, C5: 4.7uF; C_0402_1005Metric; LCSC C23733
C6: 220nF; C_0402_1005Metric; LCSC C16772
C7, C8, C10, C11, C12, C13, C14, C15, C16, C19: 10uF; C_0603_1608Metric; LCSC C194427
C9, C22: 1uF; C_0402_1005Metric; LCSC C52923
C17, C20, C23: 1nF; C_0402_1005Metric; LCSC C1523
C30: 100pF; C_0402_1005Metric; LCSC C1546
D3: KT-0603R; LED_0603_1608Metric; LCSC C2286
D4: MHT192UGCT; LED_0603_1608Metric; LCSC C389519
J1: 01x04 male P=1.27mm; PinHeader_1x04_P1.27mm_Vertical
J2: 01x05 male P=1.27mm; PinHeader_1x05_P1.27mm_Vertical
J3, J6, J7, J8: Conn_01x01_Socket; Pad_3mm_TopOnly
J4: Conn_01x06_Socket; PinSocket_1x06_P2.00mm_Vertical
R1, R3: 150m; R_2010_5025Metric; LCSC C421741
R2, R4, R5, R6, R7, R13, R15, R17, R20, R22, R24, R25, R27: 10k; R_0402_1005Metric; LCSC C25744
R11: 470R; R_0402_1005Metric; LCSC C25117
R12: 1.5k; R_0402_1005Metric; LCSC C25867
R23: 1.8k; R_0603_1608Metric; LCSC C4177
R26: 1K; R_0402_1005Metric; LCSC C11702
R29: 4.7k; R_0402_1005Metric; LCSC C25900
SW1, SW2: TS3735PA-250gf; LCSC C393946
TH1: 100k 1% NTC; R_0402_1005Metric; LCSC C236279
U4, U6, U7: AH49HSC; SOT-23; LCSC C510723
U5: GC6609; QFN-28-1EP_5x5mm_P0.5mm_EP3.75x3.75mm_ThermalVias; LCSC C16197208
U8: STM32G031G8U6; QFN-28_4x4mm_P0.5mm; LCSC C432211
U9: LM321; SOT-23-5; LCSC C19723728
U10: SP3485EN; SOIC-8_3.9x4.9mm_P1.27mm; LCSC C8963
U11: XC6206PxxxMR; SOT-23-3; LCSC C5446

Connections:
+3.3V: C5.1, C6.1, C9.1, C35.2, C37.1, J1.4, J2.5, R5.2, R6.2, R7.1, R15.2, R17.2, R29.2, SW1.1, U4.1 (VCC), U5.9 (MS1), U5.10 (MS2), U5.15 (VIO), U6.1 (VCC), U7.1 (VCC), U8.3 (VDD), U10.8 (VCC), U11.2 (VO)
+5V: C4.1, C22.1, U5.8 (VREG), U9.5 (V+), U11.3 (VI)
+24V: C3.1, C7.1, C8.1, C10.1, C11.1, C12.1, C13.1, C14.1, C15.1, C16.1, C19.1, J4.2, R27.1, U5.22 (VBB1), U5.28 (VBB1)
/index/schTop/A: J4.3, J4.5, R17.1, U10.6 (A)
/index/schTop/B: J4.4, J4.6, R2.2, U10.7 (B)
/index/schTop/DIR: U5.19 (DIR), U8.6 (PA0)
/index/schTop/FLAG1: U5.11 (FLAG1), U8.23 (PB3)
/index/schTop/HALL1: C17.1, U7.2 (VOUT), U8.11 (PA5)
/index/schTop/HALL2: C20.1, U6.2 (VOUT), U8.12 (PA6)
/index/schTop/HALL3: C23.1, U4.2 (VOUT), U8.13 (PA7)
/index/schTop/IMCONTROL: R22.1, U8.16 (PA8)
/index/schTop/LED_GREEN: R11.1, U8.2 (PC15)
/index/schTop/LED_RED: R12.1, U8.1 (PC14)
/index/schTop/OUT1A: J3.1, U5.24 (OUT1A)
/index/schTop/OUT1B: J6.1, U5.21 (OUT1B)
/index/schTop/OUT2A: J7.1, U5.26 (OUT2A)
/index/schTop/OUT2B: J8.1, U5.1 (OUT2B)
/index/schTop/OVER_VOLTAGE: R20.2, R23.2, U8.28 (PB8)
/index/schTop/PWMOV: R25.1, U8.18 (PA11/PA9)
/index/schTop/REF24: C36.1, R24.1, U8.15 (PB1)
/index/schTop/RESET: C18.1, J2.4, R15.1, SW2.1, U8.5 (PF2)
/index/schTop/RS485_D: U8.26 (PB6), U10.4 (DI)
/index/schTop/RS485_EN: R13.2, U8.19 (PA12/PA10), U10.2 (~RE), U10.3 (DE)
/index/schTop/RS485_R: U8.27 (PB7), U10.1 (RO)
/index/schTop/STEP: U5.16 (STEP), U8.7 (PA1)
/index/schTop/SWCLK: J2.2, R4.2, SW1.2, U8.21 (PA14)
/index/schTop/SWDIO: J2.3, R5.1, U8.20 (PA13)
/index/schTop/TEMPERATURE: C41.1, R29.1, TH1.1, U8.10 (PA4)
/index/schTop/UART2 RX: J1.2, U8.9 (PA3)
/index/schTop/UART2 TX: J1.3, U8.8 (PA2)
/index/schTop/~HOLDEN: R7.2, U5.14 (~HOLDEN), U8.22 (PA15)
/index/schTop/~MENABLE: R6.1, U5.2 (~ENABLE), U8.14 (PB0)
GND: C1.2, C4.2, C5.2, C6.2, C7.2, C8.2, C9.2, C10.2, C11.2, C12.2, C13.2, C14.2, C15.2, C16.2, C17.2, C18.2, C19.2, C20.2, C22.2, C23.2, C28.2, C30.2, C35.1, C36.2, C37.2, C41.2, D3.1 (K), D4.1 (K), J1.1, J2.1, J4.1, R1.1, R2.1, R3.1, R4.1, R13.1, R23.1, R26.2, SW2.2, TH1.2, U4.3 (GND), U5.3 (GND), U5.13 (CLK), U5.18 (GND), U5.25 (PGND), U5.29 (PAD), U6.3 (GND), U7.3 (GND), U8.4 (VSS), U9.2 (V-), U10.5 (GND), U11.1 (GND)
unnamed: D3.2 (A), R12.2
unnamed: D4.2 (A), R11.2
unnamed: R20.1, U9.4
unnamed: C2.1, U5.4 (CP1)
unnamed: C2.2, U5.5 (CP2)
unnamed: C1.1, R22.2, U5.17 (REF)
unnamed: R1.2, U5.23 (SENSE1)
unnamed: R3.2, U5.27 (SENSE2)
unnamed: C3.2, U5.6 (VCP)
unnamed: C30.1, R24.2, R26.1, R27.2, U9.1 (+)
unnamed: C28.1, R25.2, U9.3 (-)

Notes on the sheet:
Cutoff frequency: 1592 Hz
+24V stepper driver supply decoupling caps: Place close to the sgtepper motor driver chip
MS1 and MS2 pins: Step resolution MS2 MS1 Step resolution 0 0 1/8 0 1 1/2 1 0 1/4 1 1 1/16
${94df9340-9001-4abf-849e-0a57a0ae12d6:REFERENCE} and ${c2765680-53cb-47ff-a513-50fbdfe64cd0:REFERENCE}: Max current setting resistors: Irms = 0.092 * VREF / RSENSE 0.092 * 2.5 / 0.15 = 1.53A VREF should be maximum 2.5V The peak current that the driver is capable of is 4A and the maximum Irms is 2A
Reset
Test
+24V
SWD programming
Serial port
GND
RS485 transciever
Input power
Status LEDs
Overvoltage detection
Input power and linear regulator
Input power and RS485 connector
RS485 interface
Temperature monitoring
Servo motor stepper - Schematic top level
STM32G031G8 MCU
GC6609 Stepper driver
Hall sensors
Stepper Motor connector


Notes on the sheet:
~{MENABLE}
Stepper driver (GC6609)
Serial port
REF24
RS485 (SP3485EN)
Temp monitor
UART (USART2)
MCU (STM32G031G8U6)
IMCONTROL
ADC
UART (USART1)
PWM
GPIO
STEP
SWD (prog)
Over voltage detection
OVER_VOLTAGE
Status LEDs
Boot
PWMOV
Reset
DIR
Stepper motor
RS485 port
Servo motor stepper - Signal block diagram
Hall sensors (AH49HSC)
SWD


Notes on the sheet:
ERC flags
Servo motor stepper - Mechanical and ERC

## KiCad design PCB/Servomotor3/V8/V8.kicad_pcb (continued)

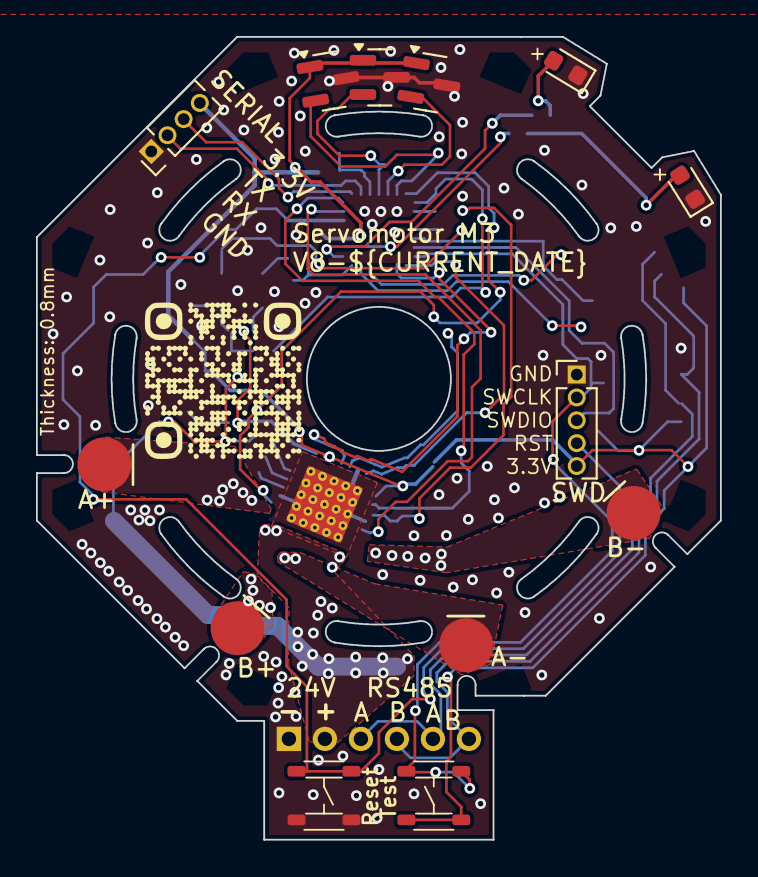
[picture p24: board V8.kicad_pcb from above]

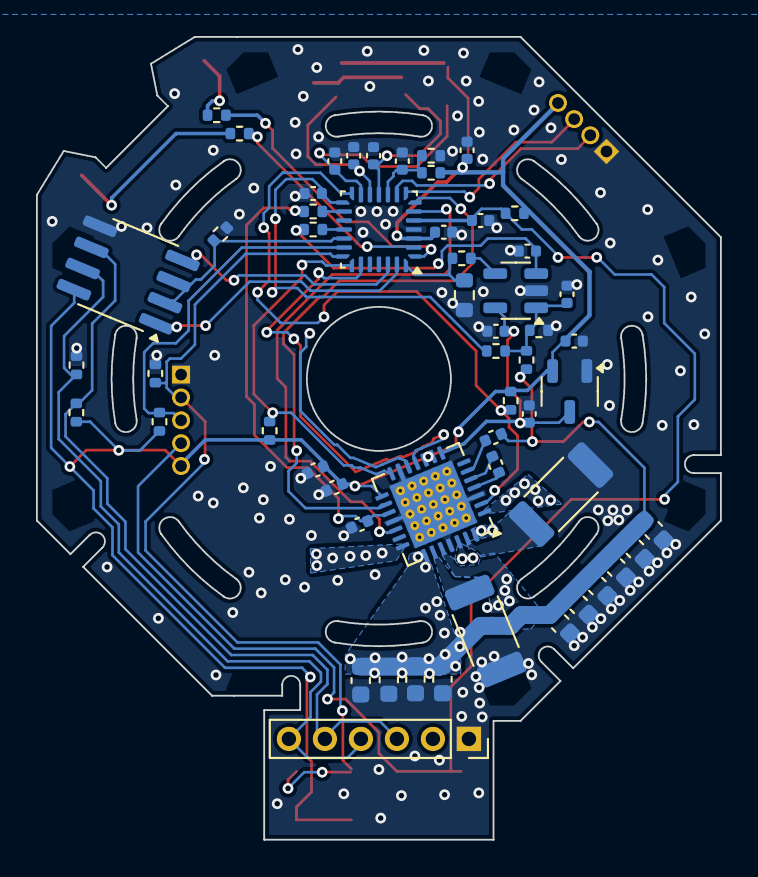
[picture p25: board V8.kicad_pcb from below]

Board: 2 copper layers, 38.0 x 44.6 mm, 68 parts (55 on the bottom side), 44 nets.

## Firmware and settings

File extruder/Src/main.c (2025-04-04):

NOTE TO SELF:

Instruction for how to update this main.c file are located in a file called update_main_c.md
You can give that file to the AI to make the necessary updates to this file if you ever do need to update this, which is unlikely

#include "stm32g0xx_hal.h"
#include <stdlib.h>
#include <stdio.h>
#include <string.h>
#include "leds.h"
#include "debug_uart.h"
#include "RS485.h"
#include "mosfets.h"
#include "ADC.h"
#include "PWM.h"
#include "CommutationTable.h"
#include "hall_sensor_calculations.h"
#include "motor_control.h"
#include "microsecond_clock.h"
#include "clock_calibration.h"
#include "error_handling.h"
#include "overvoltage.h"
#include "unique_id.h"
#include "settings.h"
#include "commands.h"
#include "product_info.h"
#include "LookupTableZ.h"
#include "global_variables.h"
#include "device_status.h"
#include "heater.h"


char PRODUCT_DESCRIPTION[] = "Servomotor";

struct __attribute__((__packed__)) firmware_version_struct {
    uint8_t bugfix;
    uint8_t minor;
    uint8_t major;
    uint8_t not_used;
};
struct firmware_version_struct firmware_version = {0, 8, 0, 0};

#define BUTTON_PRESS_MOTOR_MOVE_DISTANCE (N_COMMUTATION_STEPS * N_COMMUTATION_SUB_STEPS * ONE_REVOLUTION_STEPS)

#define PING_PAYLOAD_SIZE 10

extern uint16_t ADC_buffer[DMA_ADC_BUFFER_SIZE];
static uint64_t my_unique_id;
static int16_t detect_devices_delay = -1;


void clock_init(void)
{
    FLASH->ACR = (2 << FLASH_ACR_LATENCY_Pos) | FLASH_ACR_PRFTEN | // set two wait states, enable prefetch,
                 FLASH_ACR_ICEN;                                   // enable instruction cache

    #define M_DIVISION_FACTOR 1       // division factor (1 to 8 are valid values)
    #define N_MULTIPLICATION_FACTOR 8 // multiplication factor  (8 to 86 are valid numbers)
    #define PLLPCLK_DIVISION_FACTOR 2 // valid range is 2 to 32 // this clock must not exceed 122MHz
    #define PLLRCLK_DIVISION_FACTOR 2 // valid range is 2 to 8  // this clock must not exceed 64MHz
    // Input frequency from HSI clock is 16MHz
    // VCO frequency = input frequency * N / M
    // VCO frequency must be in the range 64 to 344MHz
    // input frequency / M must be in the range 2.66 to 16 MHz
    RCC->PLLCFGR = RCC_PLLCFGR_PLLSRC_HSI | ((M_DIVISION_FACTOR - 1) << RCC_PLLCFGR_PLLM_Pos) | (N_MULTIPLICATION_FACTOR << RCC_PLLCFGR_PLLN_Pos) |
                 RCC_PLLCFGR_PLLPEN | ((PLLPCLK_DIVISION_FACTOR - 1) << RCC_PLLCFGR_PLLP_Pos) |
                 RCC_PLLCFGR_PLLREN | ((PLLRCLK_DIVISION_FACTOR - 1) << RCC_PLLCFGR_PLLR_Pos);
    RCC->CR = RCC_CR_HSION | RCC_CR_PLLON;
    while((RCC->CR & RCC_CR_HSIRDY) == 0);
    RCC->CFGR = 2 << RCC_CFGR_SW_Pos; // set the system clock to use the PLLRCLK
    while((RCC->CFGR & RCC_CFGR_SW_Msk) != 2);

    RCC->APBENR2 |= (1 << RCC_APBENR2_SYSCFGEN_Pos); // enable the clock to the syscfg (may not be necessary to enable this)
    RCC->IOPENR = 0x3f; // enable the clock to all I/O ports
}

void systick_init(void)
{
    SysTick->LOAD  = 640000;       // set this timer to trigger the interrupt 100 times per second (ie. 64000000 / 100)
    NVIC_SetPriority (SysTick_IRQn, 3); /* set Priority for Systick Interrupt */
    SysTick->VAL   = 0UL;                                             /* Load the SysTick Counter Value */
    SysTick->CTRL  = SysTick_CTRL_CLKSOURCE_Msk |
                     SysTick_CTRL_TICKINT_Msk   |
                     SysTick_CTRL_ENABLE_Msk;                         /* Enable SysTick IRQ and SysTick Timer */



/*
    SysTick->CTRL = 0; // disable first in case it is already enabled
    SysTick->LOAD  = (uint32_t)(16000000 - 1);              // set reload register to generate interrupt at 4 Hz
//    HAL_NVIC_SetPriority(SysTick_IRQn, TICK_INT_PRIORITY, 0U);
    SysTick->VAL   = 1600000 - 1;                                             // Load the SysTick Counter Value
    SysTick->CTRL  = SysTick_CTRL_CLKSOURCE_Msk |
                     SysTick_CTRL_TICKINT_Msk   |
                     SysTick_CTRL_ENABLE_Msk;                         // Enable SysTick IRQ and SysTick Timer
*/
}

#define MODER_DIGITAL_INPUT 0
#define MODER_DIGITAL_OUTPUT 1
#define MODER_ALTERNATE_FUNCTION 2
#define MODER_ANALOG_INPUT 3 // this is the default after power up
#define OTYPER_PUSH_PULL 0 // this is the default after power up
#define OTYPER_OPEN_DRAIN 1
#define OSPEEDR_VERY_LOW_SPEED 0 // this is the default except some pins on port A
#define OSPEEDR_LOW_SPEED 1
#define OSPEEDR_HIGH_SPEED 2
#define OSPEEDR_VERY_HIGH_SPEED 3
#define PUPDR_NO_PULL_UP_OR_DOWN 0 // this is the default except on some pins on port A
#define PUPDR_PULL_UP 1
#define PUPDR_PULL_DOWN 2

void portA_init(void)
{
    #define BUTTON_PORT_A_PIN 13

    GPIOA->MODER =
            (MODER_ANALOG_INPUT       << GPIO_MODER_MODE0_Pos)  | // current measurement channel A
            (MODER_DIGITAL_OUTPUT     << GPIO_MODER_MODE1_Pos)  | // MOSFET switch disable 1
            (MODER_ALTERNATE_FUNCTION << GPIO_MODER_MODE2_Pos)  | // serial port TX
            (MODER_ALTERNATE_FUNCTION << GPIO_MODER_MODE3_Pos)  | // serial port RX
            (MODER_ANALOG_INPUT       << GPIO_MODER_MODE4_Pos)  | // hall sensor 2 ADC_IN4
            (MODER_ANALOG_INPUT       << GPIO_MODER_MODE5_Pos)  | // hall sensor 1 ADC_IN5
            (MODER_ANALOG_INPUT       << GPIO_MODER_MODE6_Pos)  | // hall sensor 3 ADC_IN6
            (MODER_ANALOG_INPUT       << GPIO_MODER_MODE7_Pos)  | // hall sensor 4 ADC_IN7
            (MODER_ALTERNATE_FUNCTION << GPIO_MODER_MODE8_Pos)  | // PWM 1A
            (MODER_DIGITAL_OUTPUT     << GPIO_MODER_MODE9_Pos)  | // heater
            (MODER_ALTERNATE_FUNCTION << GPIO_MODER_MODE10_Pos) | // PWM 3A
            (MODER_ALTERNATE_FUNCTION << GPIO_MODER_MODE11_Pos) | // PWM 4
            (MODER_ALTERNATE_FUNCTION << GPIO_MODER_MODE12_Pos) | // RS485 drive enable
            (MODER_DIGITAL_INPUT      << GPIO_MODER_MODE13_Pos) | // Button input and also SWDIO (for programming)
            (MODER_ANALOG_INPUT       << GPIO_MODER_MODE14_Pos) | // SWCLK (for programming)
            (MODER_ANALOG_INPUT       << GPIO_MODER_MODE15_Pos);

    GPIOA->OTYPER = (OTYPER_OPEN_DRAIN << GPIO_OTYPER_OT0_Pos) | // make all the pins with analog components connected open drain
                    (OTYPER_OPEN_DRAIN << GPIO_OTYPER_OT1_Pos) | // also, make the switch disable pin open drain since there is no resistor between the pin and the base of a transistor
                    (OTYPER_OPEN_DRAIN << GPIO_OTYPER_OT3_Pos) | // also, make the debug UART receive pin open drain
                    (OTYPER_OPEN_DRAIN << GPIO_OTYPER_OT4_Pos) | // may not be necessary
                    (OTYPER_OPEN_DRAIN << GPIO_OTYPER_OT5_Pos) |
                    (OTYPER_OPEN_DRAIN << GPIO_OTYPER_OT6_Pos) |
                    (OTYPER_OPEN_DRAIN << GPIO_OTYPER_OT7_Pos) |
                    (OTYPER_OPEN_DRAIN << GPIO_OTYPER_OT13_Pos) |
                    (OTYPER_OPEN_DRAIN << GPIO_OTYPER_OT14_Pos) |
                    (OTYPER_OPEN_DRAIN << GPIO_OTYPER_OT15_Pos);
    GPIOA->OSPEEDR = 0xffffffff; // make all pins very high speed
    GPIOA->PUPDR = (PUPDR_PULL_UP << GPIO_PUPDR_PUPD1_Pos) | (PUPDR_PULL_UP << GPIO_PUPDR_PUPD3_Pos); // apply pull up on the switch disable and the UART receive pin
}


void portB_init(void)
{
    GPIOB->MODER =
            (MODER_ALTERNATE_FUNCTION << GPIO_MODER_MODE0_Pos)  | // PWM 3B (TIM3 channel 3)
            (MODER_ANALOG_INPUT       << GPIO_MODER_MODE1_Pos)  | // IB sensor (TIM3 channel 4)
            (MODER_ANALOG_INPUT       << GPIO_MODER_MODE2_Pos)  | // temperature (ADC_IN10)
            (MODER_ALTERNATE_FUNCTION << GPIO_MODER_MODE3_Pos)  | // PWM 2A
            (MODER_ALTERNATE_FUNCTION << GPIO_MODER_MODE4_Pos)  | // PWM 1B(TIM3 channel 1)
            (MODER_ALTERNATE_FUNCTION << GPIO_MODER_MODE5_Pos)  | // PWM 2B(TIM3 channel 2)
            (MODER_ALTERNATE_FUNCTION << GPIO_MODER_MODE6_Pos)  | // RS485 Data out
            (MODER_ALTERNATE_FUNCTION << GPIO_MODER_MODE7_Pos)  | // RS485 Data receive
            (MODER_DIGITAL_OUTPUT     << GPIO_MODER_MODE8_Pos)  | // MOSFET switch disable 2
            (MODER_DIGITAL_INPUT      << GPIO_MODER_MODE9_Pos)  | // overvoltage digital input
            (MODER_DIGITAL_INPUT      << GPIO_MODER_MODE10_Pos) | // accelerometer int 1
            (MODER_DIGITAL_INPUT      << GPIO_MODER_MODE11_Pos) | // accelerometer int 2
            (MODER_DIGITAL_OUTPUT     << GPIO_MODER_MODE12_Pos) | // accelerometer chip select
            (MODER_DIGITAL_OUTPUT     << GPIO_MODER_MODE13_Pos) | // accelerometer SCLK
            (MODER_DIGITAL_OUTPUT     << GPIO_MODER_MODE14_Pos) | // accelerometer SDO
            (MODER_DIGITAL_INPUT      << GPIO_MODER_MODE15_Pos);  // accelerometer SDI

    GPIOB->OTYPER = (OTYPER_OPEN_DRAIN << GPIO_OTYPER_OT1_Pos)  | // current sense analog input
                    (OTYPER_OPEN_DRAIN << GPIO_OTYPER_OT2_Pos)  | // temperature analog input
                    (OTYPER_OPEN_DRAIN << GPIO_OTYPER_OT7_Pos)  | // RS485 RX pin make as open drain
                    (OTYPER_OPEN_DRAIN << GPIO_OTYPER_OT8_Pos)  | // also, make the switch disable pin open drain since there is no resistor between the pin and the base of a transistor
                    (OTYPER_OPEN_DRAIN << GPIO_OTYPER_OT9_Pos)  | // overvoltage digial input
                    (OTYPER_OPEN_DRAIN << GPIO_OTYPER_OT10_Pos) | // accelerometer int 1
                    (OTYPER_OPEN_DRAIN << GPIO_OTYPER_OT11_Pos) | // accelerometer int 2
                    (OTYPER_OPEN_DRAIN << GPIO_OTYPER_OT15_Pos) ; // accelerometer SDI
    GPIOB->OSPEEDR = 0xffffffff; // make all pins very high speed
    GPIOB->PUPDR = (PUPDR_PULL_UP << GPIO_PUPDR_PUPD7_Pos) | (PUPDR_PULL_UP << GPIO_PUPDR_PUPD8_Pos) | (PUPDR_PULL_DOWN << GPIO_PUPDR_PUPD12_Pos); // RX pin is pull up, switch disable 2 is pull up, and overvoltage pin is pull down
}


void portC_init(void)
{
    GPIOC->MODER =
            (MODER_ANALOG_INPUT       << GPIO_MODER_MODE0_Pos) |
            (MODER_ANALOG_INPUT       << GPIO_MODER_MODE1_Pos) |
            (MODER_ANALOG_INPUT       << GPIO_MODER_MODE2_Pos) |
            (MODER_ANALOG_INPUT       << GPIO_MODER_MODE3_Pos) |
            (MODER_ANALOG_INPUT       << GPIO_MODER_MODE4_Pos) |
            (MODER_ANALOG_INPUT       << GPIO_MODER_MODE5_Pos) |
            (MODER_ANALOG_INPUT       << GPIO_MODER_MODE6_Pos) |
            (MODER_ANALOG_INPUT       << GPIO_MODER_MODE7_Pos) |
            (MODER_ANALOG_INPUT       << GPIO_MODER_MODE8_Pos) |
            (MODER_ANALOG_INPUT       << GPIO_MODER_MODE9_Pos) |
            (MODER_ANALOG_INPUT       << GPIO_MODER_MODE10_Pos) |
            (MODER_ANALOG_INPUT       << GPIO_MODER_MODE11_Pos) |
            (MODER_ANALOG_INPUT       << GPIO_MODER_MODE12_Pos) |
            (MODER_ANALOG_INPUT       << GPIO_MODER_MODE13_Pos) |
            (MODER_DIGITAL_OUTPUT     << GPIO_MODER_MODE14_Pos) | // Red LED
            (MODER_DIGITAL_OUTPUT     << GPIO_MODER_MODE15_Pos);  // Green LED

    GPIOC->OTYPER = 0; // no pins are open drain
    GPIOC->OSPEEDR = 0xffffffff; // very high speed
    GPIOC->PUPDR = 0; // no pins have pulling resistors
}


void portD_init(void)
{
    GPIOD->MODER =
            (MODER_ANALOG_INPUT       << GPIO_MODER_MODE0_Pos) |
            (MODER_ANALOG_INPUT       << GPIO_MODER_MODE1_Pos) | 
            (MODER_ANALOG_INPUT       << GPIO_MODER_MODE2_Pos) |
            (MODER_ANALOG_INPUT       << GPIO_MODER_MODE3_Pos) |
            (MODER_ANALOG_INPUT       << GPIO_MODER_MODE4_Pos) |
            (MODER_ANALOG_INPUT       << GPIO_MODER_MODE5_Pos) |
            (MODER_ANALOG_INPUT       << GPIO_MODER_MODE6_Pos) |
            (MODER_ANALOG_INPUT       << GPIO_MODER_MODE7_Pos) |
            (MODER_ANALOG_INPUT       << GPIO_MODER_MODE8_Pos) |
            (MODER_ANALOG_INPUT       << GPIO_MODER_MODE9_Pos) |
            (MODER_ANALOG_INPUT       << GPIO_MODER_MODE10_Pos) |
            (MODER_ANALOG_INPUT       << GPIO_MODER_MODE11_Pos) |
            (MODER_ANALOG_INPUT       << GPIO_MODER_MODE12_Pos) |
            (MODER_ANALOG_INPUT       << GPIO_MODER_MODE13_Pos) |
            (MODER_ANALOG_INPUT       << GPIO_MODER_MODE14_Pos) |
            (MODER_ANALOG_INPUT       << GPIO_MODER_MODE15_Pos);

    GPIOD->OTYPER = 0;
    GPIOD->OSPEEDR = 0xffffffff; // very high speed
    GPIOD->PUPDR = 0;
}


// This interrupt will be called 100 times per second
void SysTick_Handler(void)
{
    #define OVERVOLTAGE_PORT_B_PIN 12

    static uint16_t toggle_counter = 0;

    toggle_counter++;
    if(toggle_counter >= 50) {
        green_LED_toggle();
        toggle_counter = 0;
    }

    if(detect_devices_delay > 0) {
        detect_devices_delay--;
    }

//    if((GPIOB->IDR & (1 << OVERVOLTAGE_PORT_B_PIN)) == 0) {
//        red_LED_off();
//    }
//    else {
//        red_LED_on();
//    }
}


void process_packet(void)
{
    uint8_t command;
    uint16_t payload_size;
    uint8_t *payload;
    uint8_t is_broadcast;

    uint64_t local_time;
    uint64_t time_from_master = 0;
//    int32_t end_position;
//    uint32_t end_time;
//    int32_t desired_position;
    uint32_t max_velocity;
    uint32_t max_acceleration;
    uint8_t capture_type;
    uint8_t n_items_in_queue;
    int32_t motor_position;
    int32_t acceleration;
    int32_t velocity;
    uint32_t time_steps;
    uint32_t frequency;
    uint64_t unique_id;
    uint8_t new_alias;
    int32_t trapezoid_move_displacement;
    uint32_t trapezoid_move_time;
    uint16_t new_maximum_motor_current;
    uint16_t new_maximum_motor_regen_current;
    uint8_t n_moves_in_this_command;
    int32_t max_homing_travel_displacement;
    uint32_t max_homing_time;
    int32_t lower_limit;
    int32_t upper_limit;
    add_to_queue_test_results_t add_to_queue_test_results;
    uint8_t ping_response_buffer[PING_PAYLOAD_SIZE + 3];
    uint8_t control_hall_sensor_statistics_subcommand;
    struct __attribute__((__packed__)) {
        uint8_t axis;
        uint8_t command;
        uint8_t size;
        hall_sensor_statistics_t hall_sensor_statistics;
    } hall_sensor_statistics_full_response;
    int8_t new_M_index;
    PID_value_t PID_values;

    #define MAX_MULTIMOVES (sizeof(uint32_t) * 8) // maximum number of moves in a multi move command. this number should be the number of bits in an uint32_t
    struct move_parameters_struct {
        union { // if the bitfield shows a 0 for this move then this parameter represents the acceleration, otherwise it represents the velocity
            int32_t acceleration;
            int32_t velocity;
        };
        int32_t time_steps;
    };
    struct multi_move_command_buffer_struct {
        uint32_t move_type_bits; // a bit field specifying the type of each move: 0 = move with acceleration; 1 = move with velocuty
        struct move_parameters_struct move_parameters[MAX_MULTIMOVES];
    };

    // There is a distinct possibility that the new packet is not for us. We will know after we see the return value of rs485_get_next_packet.
    if (!rs485_get_next_packet(&command, &payload_size, &payload, &is_broadcast)) {
        // The new packet, whatever it is, is not of interest to us and we need to clear it and return out of here
        rs485_done_with_this_packet();
        return;
    }

    if(!rs485_validate_packet_crc32()) {
        // CRC32 validation failed, allow next command and return
        rs485_done_with_this_packet();
        return;
    }
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
int main(void)
{
    clock_init();
    systick_init();
    portA_init();
    portB_init();
    portC_init();
    portD_init();
    debug_uart_init();
    rs485_init();
    microsecond_clock_init();
    adc_init();
    pwm_init();
    overvoltage_init();

    SCB->VTOR = 0x2800; // vector table is moved to where the application starts, which is after the bootloader

    my_unique_id = get_unique_id();

    load_global_settings(); // load the settings from non-volatile memory into ram for faster access
    set_motor_current_baseline(); // make sure to call this before set_max_motor_current() and make sure to call it when the MOSFETs are disabled. at the start of the program is fine
    if(global_settings.max_motor_pwm_voltage == 0xffff) {
        global_settings.max_motor_pwm_voltage = DEFAULT_MAX_MOTOR_PWM_VOLTAGE;
    }
    if(global_settings.max_motor_regen_pwm_voltage == 0xffff) {
        global_settings.max_motor_regen_pwm_voltage = DEFAULT_MAX_MOTOR_REGEN_PWM_VOLTAGE;
    }
    set_max_motor_current(global_settings.max_motor_pwm_voltage, global_settings.max_motor_regen_pwm_voltage);

    __enable_irq();

    print_start_message();

//    rs485_transmit("Start\n", 6);

//    switch_motor(); // DEBUG
//    enable_mosfets();  // DEBUG

    while(1) {
//      check_if_break_condition();
        check_if_ADC_watchdog2_exceeded();

        if(rs485_has_a_packet()) {
            process_packet();
        }

        if(detect_devices_delay == 0) {
            transmit("Transmitting unique ID\n", 23);
            transmit_detect_devices_response();
            detect_devices_delay--;
        }

        if(is_calibration_data_available()) {
            disable_motor_control_loop();
            process_calibration_data();
            transmit("Saving the settings\n", 20);
            save_global_settings();
            transmit("\nResetting\n\n", 12);
            microsecond_delay(10000);
            NVIC_SystemReset();
        }

        if(is_fast_capture_data_result_ready()) {
            print_fast_capture_data_result();
        }


        process_debug_uart_commands();
        button_logic();
        heater_logic();
    }
}

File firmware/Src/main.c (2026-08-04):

#include "stm32g0xx_hal.h"
#include <stdlib.h>
#include <stdio.h>
#include <string.h>
#include "config.h"
#include "gpio.h"
#include "leds.h"
#include "debug_uart.h"
#include "RS485.h"
#include "mosfets.h"
#include "ADC.h"
#include "temperature.h"
#include "PWM.h"
#include "hall_sensor_calculations.h"
#include "motor_control.h"
#include "microsecond_clock.h"
#include "clock_calibration.h"
#include "error_handling.h"
#include "GPIO_interrupts.h"
#include "unique_id.h"
#include "settings.h"
#include "commands.h"
#include "crc32.h"
#include "product_info.h"
#include "global_variables.h"
#include "device_status.h"
#include "portable_stdint.h"
#ifdef PRODUCT_NAME_M1
#include "commutation_table_M1.h"
#endif
#ifdef PRODUCT_NAME_M2
#include "commutation_table_M2.h"
#include "hall_sensor_constants_M2.h"
#endif
#ifdef PRODUCT_NAME_M17
#include "commutation_table_M17.h"
#endif
#ifdef PRODUCT_NAME_M23
#include "commutation_table_M23.h"
#include "current_streaming.h"
#include "current_control.h"
#endif

// Simulation-only printf function that compiles to nothing in firmware builds and optionally
// compiles to nothing if the SIMULATOR_DEBUG_PRINTING is not defined (ie. you are not debugging)
//#define SIMULATOR_DEBUG_PRINTING
#ifdef MOTOR_SIMULATION
#ifdef SIMULATOR_DEBUG_PRINTING
#include <stdio.h>
#define simulation_printf(...) printf(__VA_ARGS__)
#else
#define simulation_printf(...) ((void)0)
#endif
#else
#define simulation_printf(...) ((void)0)
#endif

//#define CERTIFICATION_TEST_MODE // if this is uncommented then the motor will start spinning soon after power is applied and will continue spinning indefinitely

char PRODUCT_DESCRIPTION[] = "Servomotor";

// Here we store the version information for the main firmware (not the bootloader firmware)
struct __attribute__((__packed__)) firmware_version_struct {
    uint8_t development;
    uint8_t bugfix;
    uint8_t minor;
    uint8_t major;
};
#define MAJOR_FIRMWARE_VERSION 0
#define MINOR_FIRMWARE_VERSION 15
#define BUGFIX_FIRMWARE_VERSION 12
#define DEVELOPMENT_FIRMWARE_VERSION 0 // this is the least significant number when it comes to versioning and is the last number on the right when printed in human readable form
struct firmware_version_struct firmware_version = {DEVELOPMENT_FIRMWARE_VERSION, BUGFIX_FIRMWARE_VERSION, MINOR_FIRMWARE_VERSION, MAJOR_FIRMWARE_VERSION};

#define BUTTON_PRESS_MOTOR_MOVE_DISTANCE ONE_REVOLUTION_MICROSTEPS

#define PING_PAYLOAD_SIZE 10

#define DEFAULT_MIDLINE 34000 // Later it might be good to have this constant autodetermined and placed into hall_sensor_constants_M17.h

extern volatile uint16_t ADC_buffer[DMA_ADC_BUFFER_SIZE];

static uint64_t my_unique_id;
static int16_t detect_devices_delay_to_answer = -1;
static int16_t detect_devices_delay_to_reenable_packet_processing = -1;
static uint32_t hall_sensor_n_points_to_capture = 0;
static uint8_t hall_sensor_point_size = 0;
static uint16_t captured_point_division_factor = 1;
static uint16_t green_led_action_counter = 0;
static uint8_t n_identify_flashes = 0;


void clock_init(void)
{
    FLASH->ACR = (2 << FLASH_ACR_LATENCY_Pos) | FLASH_ACR_PRFTEN | // set two wait states, enable prefetch,
                 FLASH_ACR_ICEN;                                   // enable instruction cache

    #define M_DIVISION_FACTOR 1       // division factor (1 to 8 are valid values)
    #define N_MULTIPLICATION_FACTOR 8 // multiplication factor  (8 to 86 are valid numbers)
    #define PLLPCLK_DIVISION_FACTOR 2 // valid range is 2 to 32 // this clock must not exceed 122MHz
    #define PLLRCLK_DIVISION_FACTOR 2 // valid range is 2 to 8  // this clock must not exceed 64MHz
    // Input frequency from HSI clock is 16MHz
    // VCO frequency = input frequency * N / M
    // VCO frequency must be in the range 64 to 344MHz
    // input frequency / M must be in the range 2.66 to 16 MHz
    RCC->PLLCFGR = RCC_PLLCFGR_PLLSRC_HSI | ((M_DIVISION_FACTOR - 1) << RCC_PLLCFGR_PLLM_Pos) | (N_MULTIPLICATION_FACTOR << RCC_PLLCFGR_PLLN_Pos) |
                 RCC_PLLCFGR_PLLPEN | ((PLLPCLK_DIVISION_FACTOR - 1) << RCC_PLLCFGR_PLLP_Pos) |
                 RCC_PLLCFGR_PLLREN | ((PLLRCLK_DIVISION_FACTOR - 1) << RCC_PLLCFGR_PLLR_Pos);
    RCC->CR = RCC_CR_HSION | RCC_CR_PLLON;
    while((RCC->CR & RCC_CR_HSIRDY) == 0);
    RCC->CFGR = 2 << RCC_CFGR_SW_Pos; // set the system clock to use the PLLRCLK
    while((RCC->CFGR & RCC_CFGR_SW_Msk) != 2);

    RCC->APBENR2 |= (1 << RCC_APBENR2_SYSCFGEN_Pos); // enable the clock to the syscfg (may not be necessary to enable this)
    RCC->IOPENR = 0x3f; // enable the clock to all I/O ports
}

void systick_init(void)
{
    SysTick->LOAD  = 640000;       // set this timer to trigger the interrupt 100 times per second (ie. 64000000 / 100)
    NVIC_SetPriority (SysTick_IRQn, 3); /* set Priority for Systick Interrupt */
    SysTick->VAL   = 0UL;                                             /* Load the SysTick Counter Value */
    SysTick->CTRL  = SysTick_CTRL_CLKSOURCE_Msk |
                     SysTick_CTRL_TICKINT_Msk   |
                     SysTick_CTRL_ENABLE_Msk;                         /* Enable SysTick IRQ and SysTick Timer */
}


// This interrupt will be called 100 times per second
void SysTick_Handler(void)
{
    #define OVERVOLTAGE_PORT_B_PIN 12

    if(n_identify_flashes == 0) {
        if(green_led_action_counter < 99) {
            green_LED_off();
            green_led_action_counter++;
        }
        else if(green_led_action_counter < 100) {
            green_LED_on();
            green_led_action_counter++;
        }
        else {
            green_led_action_counter = 0;
        }
    }
    else {
        if(green_led_action_counter < 3) {
            green_LED_on();
            green_led_action_counter++;
        }
        else if(green_led_action_counter < 8) {
            green_LED_off();
            green_led_action_counter++;
        }
        else {
            green_led_action_counter = 0;
            n_identify_flashes--;
        }
    }

    if(detect_devices_delay_to_answer > 0) {
        detect_devices_delay_to_answer--;
    }
    if(detect_devices_delay_to_reenable_packet_processing >= 0) {
        detect_devices_delay_to_reenable_packet_processing--;
    }

//    if((GPIOB->IDR & (1 << OVERVOLTAGE_PORT_B_PIN)) == 0) {
//        red_LED_off();
//    }
//    else {
//        red_LED_on();
//    }
}


void set_led_test_mode(uint8_t colours)
{
    __disable_irq();
    disable_mosfets();
    if (colours & 1) {
        green_LED_on();
    }
    if (colours & 2) {
        red_LED_on();
    }
    while(1);
}


void copy_input_parameters_and_check_size(void *destination, const void *source, uint32_t destination_size, uint32_t source_size)
{
    if (destination_size != source_size) {
        fatal_error(ERROR_COMMAND_SIZE_WRONG);
    }
    memcpy(destination, source, destination_size);
}
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

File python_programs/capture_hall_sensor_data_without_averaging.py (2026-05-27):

#!/usr/bin/env python3

import servomotor
from servomotor.device_detection import detect_devices_iteratively
import time
import argparse
import matplotlib.pyplot as plt
import numpy as np
import os

# Number of detection iterations for autodetection
N_DETECTION_ITERATIONS = 6

# Output directory for hall sensor data files
HALL_DATA_DIR = "hall_sensor_data_no_avg"

OUT_BIN_FILENAME = "hall_calibration_raw_data_no_avg.bin"
OUT_TEXT_FILENAME = "hall_calibration_one_rotation_no_avg.txt"

# Link & firmware constants (must match firmware).
RS485_BAUD_RATE = 230400               # RS485.c:159 sets BRR=278 at 64MHz SYSCLK -> 230400 bps
UART_BITS_PER_BYTE = 10                # 8N1: 1 start + 8 data + 1 stop
# The capture command's timeStepsPerSample counts TIM16 ISR ticks (= PWM_FREQUENCY),
# NOT motor_control.h's TIME_STEPS_PER_SECOND (which is PWM_FREQUENCY >> 1 = 15625 Hz).
# capture_logic is called from motor_movement_calculations -> TIM16_IRQHandler, which
# fires at PWM_FREQUENCY = PWM_CLOCK_FREQUENCY / PWM_PERIOD_TIM16 = 64MHz / 2048 = 31250 Hz.
# This matches the runtime value returned by get_update_frequency() in motor_control.c.
TIM16_ISR_RATE_HZ = 31250
HALL_PEAK_FIND_THRESHOLD = 2000        # motor_control.c (M17/M23): threshold used by the calibration peak-finder

def plot_data(data, save_png=False, png_filename=None):
    col1, col2, col3 = zip(*data)

    X = list(range(len(data)))

    fig, axs = plt.subplots(4, 1, figsize=(8, 12))

    axs[0].plot(X, col1)
    axs[0].set_title('Column 1')
    axs[0].set_ylabel('Y-axis value')

    axs[1].plot(X, col2)
    axs[1].set_title('Column 2')
    axs[1].set_ylabel('Y-axis value')

    axs[2].plot(X, col3)
    axs[2].set_title('Column 3')
    axs[2].set_ylabel('Y-axis value')

    axs[3].plot(X, col1, label="Column 1")
    axs[3].plot(X, col2, label="Column 2")
    axs[3].plot(X, col3, label="Column 3")
    axs[3].set_title('Hall Calibration Data (no averaging)')
    axs[3].set_xlabel('Row number')
    axs[3].set_ylabel('Y-axis value')

    plt.tight_layout()

    if save_png and png_filename:
        # Create hall_sensor_scans directory if it doesn't exist
        os.makedirs('hall_sensor_scans', exist_ok=True)

        # Save the plot as PNG
        png_path = os.path.join('hall_sensor_scans', png_filename)
        plt.savefig(png_path, dpi=300, bbox_inches='tight')
        print(f"Plot saved as: {png_path}")

    if not save_png:
        plt.show()
    else:
        plt.close()  # Close the figure to free memory when saving

def calculate_crc32(data):
    """Calculate CRC32 checksum for a byte array"""
    import zlib
    return zlib.crc32(data) & 0xffffffff


def parse_hall_samples(data):
    """Parse the raw 6-byte-per-point payload into an (N, 3) uint16 numpy array."""
    n_points = len(data) // 6
    arr = np.frombuffer(data[:n_points * 6], dtype=np.uint16).reshape(n_points, 3)
    return arr


def print_capture_statistics(samples, total_bytes, elapsed_s,
                              n_points_requested, time_steps_per_sample,
                              n_samples_to_sum, division_factor,
                              channels_bitmask, bytes_per_point):
    """Print communication, link-utilization and per-channel noise statistics."""

    n_points = samples.shape[0]
    expected_capture_s = (n_points * time_steps_per_sample) / TIM16_ISR_RATE_HZ
    configured_sample_rate_hz = TIM16_ISR_RATE_HZ / time_steps_per_sample
    measured_sample_rate_hz = n_points / elapsed_s if elapsed_s > 0 else float('nan')
    max_uart_bytes_per_s = RS485_BAUD_RATE / UART_BITS_PER_BYTE
    payload_bytes_per_s = total_bytes / elapsed_s if elapsed_s > 0 else float('nan')
    payload_bits_per_s = payload_bytes_per_s * UART_BITS_PER_BYTE
    pct_of_baud = (payload_bits_per_s / RS485_BAUD_RATE) * 100.0

    print()
    print("=" * 68)
    print("CAPTURE STATISTICS")
    print("=" * 68)
    print("Capture parameters:")
    print(f"  captureType                = 1 (raw hall sensor readings)")
    print(f"  nPointsToRead              = {n_points_requested}")
    print(f"  channelsToCaptureBitmask   = 0x{channels_bitmask:02X} ({bin(channels_bitmask)})")
    print(f"  timeStepsPerSample         = {time_steps_per_sample}")
    print(f"  nSamplesToSum              = {n_samples_to_sum}  (1 = NO averaging)")
    print(f"  divisionFactor             = {division_factor}")
    print()
    print("Timing:")
    print(f"  Configured sample rate     = {configured_sample_rate_hz:9.3f} Hz "
          f"(TIM16 ISR rate {TIM16_ISR_RATE_HZ} Hz / timeStepsPerSample={time_steps_per_sample})")
    print(f"  Theoretical capture time   = {expected_capture_s:9.3f} s")
    print(f"  Measured elapsed time      = {elapsed_s:9.3f} s")
    if expected_capture_s > 0:
        overhead_s = elapsed_s - expected_capture_s
        print(f"  Overhead vs theoretical    = {overhead_s:+9.3f} s "
              f"({(overhead_s / expected_capture_s) * 100:+.2f} %)")
    print(f"  Measured point rate        = {measured_sample_rate_hz:9.3f} Hz")
    print()
    print("Link utilization:")
    print(f"  RS485 baud rate            = {RS485_BAUD_RATE} bps "
          f"({UART_BITS_PER_BYTE} bits/byte 8N1 -> max {max_uart_bytes_per_s:.0f} B/s payload)")
    print(f"  Points received            = {n_points}")
    print(f"  Bytes per point            = {bytes_per_point}")
    print(f"  Total payload bytes        = {total_bytes}")
    print(f"  Effective payload rate     = {payload_bytes_per_s:9.1f} B/s "
          f"= {payload_bits_per_s:9.0f} bps  ({pct_of_baud:5.2f} % of baud)")
    print()

    n_channels = samples.shape[1]
    channel_labels = [f"Hall{i+1}" for i in range(n_channels)]

    print("Per-channel value statistics:")
    print(f"  {'':12s}" + "".join(f"{lbl:>12s}" for lbl in channel_labels))
    for name, fn in [
        ("min",      lambda c: int(c.min())),
        ("max",      lambda c: int(c.max())),
        ("peak-pk",  lambda c: int(c.max() - c.min())),
        ("mean",     lambda c: float(c.mean())),
        ("median",   lambda c: float(np.median(c))),
        ("std dev",  lambda c: float(c.std())),
    ]:
        row = f"  {name:12s}"
        for ch in range(n_channels):
            v = fn(samples[:, ch])
            if isinstance(v, float):
                row += f"{v:12.2f}"
            else:
                row += f"{v:12d}"
        print(row)
    print()

    # First-difference statistics: during motion, consecutive samples differ by
    # (deterministic signal change + noise). A noise spike that exceeds the peak-find
    # threshold could fire a phantom extremum during calibration.
    deltas = np.diff(samples.astype(np.int32), axis=0)
    abs_deltas = np.abs(deltas)
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

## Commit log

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2021-09-26 Adding the essential parts of the toolchain needed for compiling the current version (~35MB) Adding build scripts and programming scripts. Can build now (on Mac) with no dependencies except a bash sh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
    [main.c, settings.c]
2021-09-29 Bootloader is now working and an application can be uploaded and burned through the RS485 Adding some python test programs.
    [calibration.py, main.c, settings.c]
2021-10-05 Product information (product code, hardware revision, serial nubemr, and unique ID) are now stored in a specific place in flash memory and burned when the bootloader is programmed.
    [main.c]
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2021-10-17 Send the signal that the command is finished sooner, to prevent command overflow fatal error.
    [main.c]
2021-10-25 Adding a new way to go into closed loop mode without requireing the motor to spin, only to vibrate. Adding a system reset command, so that the bootloader can be entered automatically by the firmware 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
    [main.c]
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2021-11-02 Putting in checks to make sure the velocity or acceleration are not exceeded, fatal error if it happens Some work started on a new calibraton routine, but it is incomplete.
    [main.c]
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2021-11-16 Swapped the debug UART and the RS485 UART Added a Makefile to build the firmware Added a precompiled make that can run on MacOS Improved some testing programs to have better command line options Star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
    [calibration.py, enable_or_disable_motor.py, main.c]
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2021-11-21 Adding a function to capture hall sensor data at high speed (but only for a short time) and print them to the debug port. Some fixes so that we are able to capture hall sensor data while the motor is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
    [main.c]
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2021-11-23 Adding a feature to capture hall sensor data either by pressing f on the debug console (to capture immediately) or by pressing t (to capture continuously but print out when a trigger occurs). Fixing 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
    [main.c]
2021-11-24 Using a moving average to compute the velocity. Fixing the compensation for the applied voltage at increased velocity. Some improvements in code.
    [main.c]
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2021-11-30 A lot of changes. The biggest ones are: Overvoltage protection added to protect the MOSFETs (needs version 20 of the motor or higher). A new firmware will only be accepted if the model code and the f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
    [main.c, settings.c]
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2021-12-09 Fixing a bug with the multimove command where the wrong variable was being used to get the move type Improving the homing function so that it works
    [main.c]
2021-12-16 Implementing movement safety limit. There is a new command to set the limits. Also, the motor will calculate in advance if a safety limit wil be hit and will throw an error if it predicts one.
    [main.c]
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2022-04-11 Preventing command overflow error by disabling the receive interrupt until the current command is processed. This is not tested yet.
    [main.c]
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2022-07-02 Fixing some bugs, especially one where the bootloader could only receive one command and nothing else until reset.
    [main.c]
2022-07-20 Adding commands to be able to collect and read some statistics for the hall sensors Fixing bugs
    [main.c]
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2022-10-08 Refactoring of the python program to allow execution of motor commands. Fixing a problem where the mosfet driver would cause shooth-through when mosfets are enabling (by setting PWM to 65535, which c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
    [main.c]
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2023-05-21 A lot of improvements done on the bootloader and several of the products. Possible bug fixes. Now can build M1 and M2 firmware by specifying the desired product. These two firmwares should be working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
    [main.c]
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2023-06-16 Adding V27 for Servomotor 1, which fixes the problem where the Vcc for the high side of the mosfet driver was not being switch by the SD (switch disable) signal.
    [BOM_servo_motor.csv, Checklist_ServomotorV27.xlsx, eBOM_ServoMotor_Rev1.xlsx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]
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2023-07-10 Revamp of how the motor enters closed loop mode. Now there is a quick vibration to determine one of four posible commutation positions. I believe this way is more reliable.
    [main.c]
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2023-12-11 Fix a bug where the TIME_RESET_COMMAND would trigger a control loop took too long error.
    [main.c]
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2023-12-19 Solved some major issues with the go to closed loop feature. Improved some test programs. Adding the Identify command.
    [BOM-M3-V4-10-12-23.csv, M3-V4.kicad_pcb, M3-V4.kicad_sch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]
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2023-12-22 Identify will now flash rapidly for three seconds to make it more obvious. When setting the device alias, there won't be a fatal error anymore. instead, the device will reset afger writing to flash. 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
    [main.c, settings.c]
2024-01-09 Adding the convertion to degrees C in the extruder project Extruder heater will now always shut off when there is a fatal error
    [main.c]
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2024-05-15 Adding support for Servomotor#4 Adding test mode for LEDs where they all turn on Bug fixes
    [BOM-M4-V1-07-03-24.csv, M4-V1.kicad_pcb, M4-V1.kicad_sch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]
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2024-05-16 Adding overtemperature protection and ability to read the temperature with a command Bug fixes and code improvements Added a few new tests to a new folfer called motor_tests
    [servo_motor.kicad_sch]
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2024-09-25 fixing deficiencies with the servomotor module updating magnetic disk machine code to use new servomotor module updating motor_command.py utility that controls the motor to use the servomotor module 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
    [PowerBlockDiagram.kicad_sch, V3.kicad_pcb, V3.kicad_sch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]
2024-09-27 motor_commands.json moved to the servomotor module and is now used for reading in all the commands. same with data_types.json cleanups of some print statements and improved verbose logic timeout give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
    [motor_commands.json]
2024-10-10 Remove some commented out code that we don't need Removed unused files from the bootloader Added "overcurrent" and "PWM too high" fatal errors Improvements and bug fixes in the servomotor Python modu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
    [motor_commands.json]
2024-10-12 Adjusting parameters of GC6609 chip in Servomotor#3 to decrease high pitch noise Supply voltage calibration Removing unneeded code Overvoltage protection calibration Rename of PWM_PERIOD into two dif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
    [main.c]
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2024-10-18 Implementing 96 bit position instead of 64 bit, so that we never hit the limit even after decades of running Changing certain parameters to 64 bit instead of 32-bit, where appropriate Implementing a 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
    [motor_commands.json]
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2024-11-13 Changing to using the AT5833 motor driver chip Test program for handling arithmatic with i96 types Adding error codes for if the position deviated too much from the expected Magnetic disk assembly ma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
    [PowerBlockDiagram.kicad_sch, V11RC3.kicad_pcb, V11RC3.kicad_sch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]
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2024-11-16 iStrangely, this firmware does not work. Motor cannot enable and spin. DON'T USE THIS FIRMWARE. Adding a test program for testing the PID controller Adding a "Set Max allowable position deviation" co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
    [V11RC3.kicad_pcb, motor_commands.json]
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2024-11-23 All calls to fatal_error() no longer have a hard coded magic number and instead us an enum in there. Debug printing from the servomotor will be disabled by default, and will only become enabled if a 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
    [motor_commands.json]
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2024-11-24 Fixing the Makefile so that the make operation succeeds inside the VSCode terminal. Fixing some code issues with the bootloader to let it compile. Adding a new program called buid_and_program.sh for 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
    [main.c]
2024-11-24 Fixing a compiler error with main.c Adding checking and proper error message if no GPIO configuration exists for the product being built. Adding some built bootloaders for harware that we currently h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
    [gpio.h, main.c]
2024-11-25 Fixing issues with the GPIO initialization in the bootloader and the application firmware. Fixing the build_and_program.sh script that builds the bootloader, because it was not adding device specific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
    [main.c]
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2024-12-05 Changing the GPIO pin that is used for the test button, so that the test button can pull to GND rather than 3.3V, which simplifies routing on the PCB Glue dispensing machine program updated to use th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
    [PowerBlockDiagram.kicad_sch, V11RC4.kicad_pcb, V11RC4.kicad_sch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]
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2024-12-10 GPIO configuration changes for Servomotor#3 V11RC4 Get debug values command now also returns the number of time steps left in the current move Fixed a bug where the queue was being slightly corrupted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
    [glue_machine_calibration.json, motor_commands.json]
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2025-01-02 For the software compatibility 3 and above (Servomotor#3 V11), we now have a setting for the MS1 and MS2, to determine if the motor will run using 16 step or 265 step interpolation. for now, continue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
    [PCB_outline_250101.DXF, PowerBlockDiagram.kicad_sch, V11.kicad_pcb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]
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2025-01-10 Beginnings of a Arduino library and a C SDK. A partially working motor simulator that visualizes the motor spinning and which uses a lot of the actual servomotor firmware. load_global_settings and sa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
    [main.c, settings.c]
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2025-02-13 Hall sensors are now simulated in the simulator, and so the shaft rotation should register in the hall sensor position, however, this seems to not work right quite yet. Makefile updates to include mo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
    The SysTick timer now runs correctly (at 100 Hz) and as a result the "Detect devices" command correctly runs after the random delay. MOSFETs disable upon system reset, because we now correctly update the IDR registers when the BSSR registers have bits set.
    CRC32 is now calculated correctly when a "Detect devices" command is is
    [main.c, settings.c]
2025-02-17 The calculation of the hal sensors' ADC values is working correctly now and the encoder will correctly calculate the motor shaft's position. Removal of redundant variables that store the shaft angle.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
    [main.c]
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2025-03-01 Fixing certain conversion constants for the velocity and acceleration that were wrongly calculated. Changed the unit conversion function to have a direction input to determine if it converts to or fr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
    [gpio.h, main.c]
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2025-03-02 Renaming some cases of ServoMotor to Servomotor Renaming the examples Fixing a bunch of compiler warnings in the motor simulator compilation
    [GPIO_interrupts.c, gpio.h, main.c]
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2025-03-07 Fix multiMove functionality and add comprehensive testing Modifications were done to Servomotor.cpp and Servomotor.h directly, and we have not gotten to the changes required to autogenerate these yet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
    [motor_commands.json]
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2025-03-12 Breaking changes to the protocol: - the first byte in any transmission is not a bit more complex: - we now have the "All alias" value to be 127 - 126 is not the response value - 125 is reserved for a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
    [main.c]
2025-03-13 Implemented extended addressing in the motor's firmware Implemented support for extended addressing in the Python servomotor library and tested it motor_command.py supports extended addressing too, a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
    [main.c]
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2025-03-24 INCOMPLETE FUNCTIONALITY being committed Things won't compile and everything is broken Breaking changes to the protocol: packet size byte comes first, then the alias, then the command, then the paylo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
    [main.c]
2025-03-25 Fixing the bootloader for the STM32G030 so that it uses the new protocol and compiles, although it is untested Adding some documentation about how to bring old main.c files up to date to use the new 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
    [main.c]
2025-03-28 Adding a test program for testing the CRC32 code inside the motor simulator Adding a program that can send arbitrary bytes to a serial port. It is for testing the RS485 receive logic Bug fix in the C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
    [motor_commands.json]
2025-03-28 Refactored the logic around CRC32 checking and where the crc32_enabled variable is kept. Added a second statistic about packet decoding failures Changed the command name to get the statistics of the 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
    [motor_commands.json]
2025-03-29 "Set device alias" and "Identify" commands no longer take a unique ID as an explicit parameter. Not needed anymore because the protocol now has a built in extended addressing mode "Get update frequen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
    [motor_commands.json]
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2025-03-31 Implementing a new upgraded "Capture hall sensor data" command that now takes in many more parameters to give the user a lot of flexibility in what is captured The captured data is returned back usin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
    [motor_commands.json]
2025-03-31 A new reworked capture_hall_sensor_data.py program to get the hall sensor reading while spinning the motor, so that the sensors and magnetic disk can be verified to work correctly. communication.py i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
    [capture_hall_sensor_data.py, main.c]
2025-04-01 Fixed a typo in "suggest_setitngs.py" Adding a new fatal error code called ERROR_CAPTURE_BAD_PARAMETERS to deal with bad parameters sent in when trying to capture hall sensor data Initializing all st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
    [main.c]
2025-04-02 Fixing a problem in at least one command where a fault occurred because of wrong memory alignment when copying data. The fix is to use memcpy to copy the data. During communication, the green LED wil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
    [main.c]
2025-04-03 When calling the Set device alias command, now we will check for a valid alias and prevent invalid aliases from being assigned Fixed a bug where the Detect devices commands sent incomplete data becau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
    [main.c]
2025-04-04 "Multi Move" renamed to "Multimove" to make it more correct English-wise Fixed a bug with handling of the Multimove command where the compute size was wrong Fixed a compile error in the simulator Fix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
    [motor_commands.json]
2025-04-06 Working on updating the Arduino Library so that it uses the new protocol. Changes done and tests pass. New print variant in the Arduino emulator to support printing hex numbers Adding CRC32 calculati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
    [main.c]
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2025-04-13 Fixed some bugs in the Servomotor.h autogeneration related to the AMPS unit Now the new autogeneration program is also trying to generate Servomotor.cpp, although there are still some issue with it R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
    [motor_commands.json]
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2025-04-23 Adding a new test to test the "Set device alias" command Adding a program that can run many tests in one shot called run_all_tests.py Adding a piece of documentation that has a list of the various te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
    [motor_commands.json]
2025-04-26 Adding a new test program for testing the "Get product info" command in the bootloader and in the application Fixing a bug where the "Get product info" command caused a segmentation fault in the moto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
    [motor_commands.json]
2025-06-12 Modifying the "Get firmware version" command to also return a flag to indicate that we are in the main firmware or the bootloader. Bootloader will also respond to this command and give it's version n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
    [1.2.kicad_pcb, 1.2.kicad_sch, 1.3.kicad_pcb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]
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2025-06-20 New firmware released, nearly the same like the previous version, mainly used for testing the firmware upgrade program Fair bit of clean up around for the alias and unique ID are handles, not cleanly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
    [main.c]
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2025-06-28 Improvements on the detection of connected devices. Solve the issue where the device got into the bootloader unexpectedly. Bumping firmware version a little Code cleanups Releasing a firmware for har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
    [capture_hall_sensor_data.py, main.c, ping_blast.py]
2025-07-01 A significan change relating to how the device responds when there is no error and when there is a fatal error: No error, responds with just two bytes + 4 bytes crc32 if enabled Normal response has a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
    [motor_commands.json]
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2025-07-02 Making improvements to the bootloader so that it takes the new behaviour similar to the main firmware, which is: 1. If in a fatal error state then respond with a fatal error code to any command issue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
    [main.c]
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2025-07-25 Adding another counter to count communication errors, the number of times that the first bit was not 1 Releasing a new firmware version with that additional counter All Python tests pass Improved the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
    [motor_commands.json]
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2025-08-30 Making a new version of the datasheet where some corrections are made and also some improvements.
    [gpio_M17.c, gpio_M23.c]
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2025-09-05 Updating the Communication.cpp module so that it handles the new protocol All tests pass now. Re-autogenerated the library files so that some commands are updated, like "get communication statistics"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
    [1.0.kicad_pcb, 1.0.kicad_sch, PCB_outline_250101.DXF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]
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2025-12-28 Fix the program that captures the hall sensor data to work more reliably in the case of an uncalibrated motor or one with faulty magnets or hall sensory. basically, we allow a huge position deviation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
    [capture_hall_sensor_data.py]
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2026-02-02 Fixing the test mode for the LEDs so that we are able to turn on any combination
    [main.c]
2026-02-03 Chaning GPIO configs for servomtor M23 for the latest version M23 control works a bit differently: not need for TIM3 anymore Renaming some files from M4->M23 Adjusting the test modes a bit so that we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
    [main.c]
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2026-02-03 Bug fixes with the communication module in the Arduino Library Rename of M4 to M23 in some places Some GPIO config changes for hardware version 0.10 for Servomotor M23 The generate_product_info progr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
    [gpio_M23.c]
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2026-05-18 Add simulated hard-stop case to the homing test
    test_homing.py previously only verified homing that runs the full
    commanded distance. It now also verifies homing that ends early on a
    hard stop. The test motor has no physical end stop, so one is simulated
    by dropping the motor current mid-homing until the motor can no longer
    follow the motion profile, which triggers the firmware's following-error
    crash detection. The new verification checks the motor genuinely homed
    first, then stopped early in both distance and time.
    Also fix the "Set maximum motor current" command description in
    motor_commands.json: it wrongly claimed the values are stored in
    non-volatile memory. They are held in RAM and r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
    [motor_commands.json]
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2026-05-27 M23 firmware: redesign current_streaming to 9-byte checksum frame, add current_control PI module (gated behind commented-out M23_CURRENT_CONTROL), configure TIM1 for center-aligned PWM with OC3REF AD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
    [main.c]
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2026-06-02 Add overvoltage-protection production test modes (cmd 36 modes 74/75); fw 0.15.1.0
    Phase 10 of the production test plan needs firmware support to set the
    overvoltage-protection threshold to two fixed voltages so a 24 V rack can
    verify the OV comparator + threshold PWM:
    - test mode 74: set OV threshold to 22 V (must trip on a 24 V rack)
    - test mode 75: set OV threshold to 26 V (must NOT trip on a 24 V rack)
    The threshold is the TIM1_CH4 PWM (PA11 on M17) feeding the OV comparator,
    whose trip already raises fatal_error(ERROR_OVERVOLTAGE) via EXTI. Factored
    the threshold computation out of pwm_init() into set_overvoltage_threshold(),
    which uses the existing per-product OVERVOLTAGE_PROTECT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
    [motor_commands.json]
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2026-06-15 Add 90°C thermal test mode (fw 0.15.2.0) and wire it into Phase 11
    Firmware:
    - New "Test mode" 76 (cmd 36) raises the overtemperature cutoff from ~80°C
    to ~90°C so the driver IC is verified to have thermal margin under load.
    The cutoff is now a runtime variable (set_overtemperature_test_mode); a
    system reset restores the default, mirroring the overvoltage test modes.
    - Threshold 10773 ADC ≈ 90°C, computed against the temperature lookup table.
    - Bump firmware version 0.15.1.0 -> 0.15.2.0; add the M17 release binary.
    Production test system:
    - Phase 11 broadcasts test mode 76 at the start so the thermal run goes to
    ~90°C, then runs to fatal error as before.
    - Raise overtemp_thre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
    [motor_commands.json]
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2026-06-23 Fix strict-aliasing/uninitialized warnings in motor_control.c; release fw 0.15.3.0
    Replace all int96_t position type-punning (pointer casts of mid/high into an
    int64_t) with an anonymous union exposing the upper 64 bits as `.position`.
    This removes 14 -Wstrict-aliasing warnings and 1 -Wuninitialized warning from
    the M17 build. The union access is well-defined and at -O3 compiles smaller and
    faster (.text -476 B, -216 instructions) because the old casts forced int64
    stack spills that the union now keeps in registers.
    Also fixes two latent bugs the cleanup surfaced:
    - print_position(): out-of-bounds stack write via ((int64_t*)&x)[1] -- wrong
    cast stride wrote 8 bytes past the local (no alia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
    [main.c]
2026-06-30 Datasheet v1.9: imperative command voice, grammar/spelling fixes, table fix
    - Rewrite all motor_commands.json command descriptions in consistent
    operator-imperative voice (e.g. "Disable the MOSFETs", "Get the status
    of the motor"). 44 of 48 descriptions updated.
    - Fix spelling: seconde->second, significan->significant, teels->tells,
    ovserved->observed; normalize MOSFETS->MOSFETs.
    - Fix grammar/punctuation: add missing end periods, hyphenate closed-loop
    and power-on, tighten run-ons; technical content unchanged.
    - specs.py: widen the Mechanical Specifications first column to 24% so
    "Dimensions (LxW)" no longer overflows into the value column (matches
    the Technical Specifications t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
    [motor_commands.json]
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2026-07-11 PID improvement: anti-windup + overflow hardening + D-filter fix; fw 0.15.3.4
    Root causes fixed (all bench-confirmed, plan doc sections 1-18):
    - kI>=10 oscillation was integrator-fueled stick-slip windup: integral
    authority clamped to 25% of output authority + back-calculation
    anti-windup at pid_output_limit (kI=25 post-move RMS 6,865 -> ~35)
    - "D does nothing" was a sticky floor-decay bug: (lpf*31)>>5 never decays
    values -31..-1, leaving a kD-proportional D bias (-85k at kD=175k);
    decay now rounds toward zero; output shift rounds to nearest
    - 15 UB integer-overflow sites hardened: error input clamp +/-2^29,
    authority cap 800e6, gains capped to INT32_MAX, ki capped for railed-
    in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
    [e5c_dissect.csv, hardened_ki25_kd350k.csv, hardened_standstill.csv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]
2026-07-20 Firmware 0.15.9.0: fatal-error reply-race fix, validation hardening, spec-aligned limits
    Fixes hardware-verified bugs BUG-17..21, BUG-23, BUG-24 (registry in
    BUGS_FOUND_2026-07-09.md, experiments in EXPLORATION_LOG_2026-07-16.md):
    - BUG-17/19/20 (0.15.5.0): a fatal error firing while a reply was mid-
    transmission truncated the reply and could deadlock the device until power
    cycle (fatal loop's rs485_transmit_error_packet spun in the transmit entry
    wait with interrupts off). fatal_error() now drains in-flight TX by hand
    (new bounded rs485_drain_transmit()), MOSFETs still disabled first; the
    deferred error reply is suppressed once any reply was issued (flag cleared
    at every reply-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
    [main.c]
2026-07-20 Command/error JSONs rewritten from firmware ground truth; library fixes; units regenerated
    - error_codes.json: all 55 entries rewritten from traced fatal_error() call
    sites and adversarially verified; version-scoped notes through fw 0.15.9.0.
    - motor_commands.json: all 48 descriptions and parameter texts rewritten from
    byte-verified firmware handlers, then refined by three audit passes and 44
    hands-on hardware experiments (queue accounting, planner algebra, capture
    aliasing, fleet-scale rules, wire-format caps, defaults history).
    - M3.py: seconds-first data-driven default units; time-type wire rescaling per
    parameter InternalUnit; 16-hex-digit unique-ID constructor policy with
    re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
    [motor_commands.json]
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

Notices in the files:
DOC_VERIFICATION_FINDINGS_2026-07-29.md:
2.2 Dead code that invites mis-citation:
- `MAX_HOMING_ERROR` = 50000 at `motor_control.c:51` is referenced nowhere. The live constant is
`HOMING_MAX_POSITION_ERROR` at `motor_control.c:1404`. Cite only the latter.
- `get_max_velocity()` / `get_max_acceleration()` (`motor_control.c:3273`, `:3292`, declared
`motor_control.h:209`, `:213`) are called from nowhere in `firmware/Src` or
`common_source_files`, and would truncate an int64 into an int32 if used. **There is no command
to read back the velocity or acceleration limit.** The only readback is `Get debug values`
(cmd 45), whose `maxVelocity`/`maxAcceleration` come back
